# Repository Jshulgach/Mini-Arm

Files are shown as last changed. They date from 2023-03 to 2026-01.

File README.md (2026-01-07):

# Mini-Arm
<!-- ![](assets/assembly2.png) -->
<div align=center>

<p align="center">
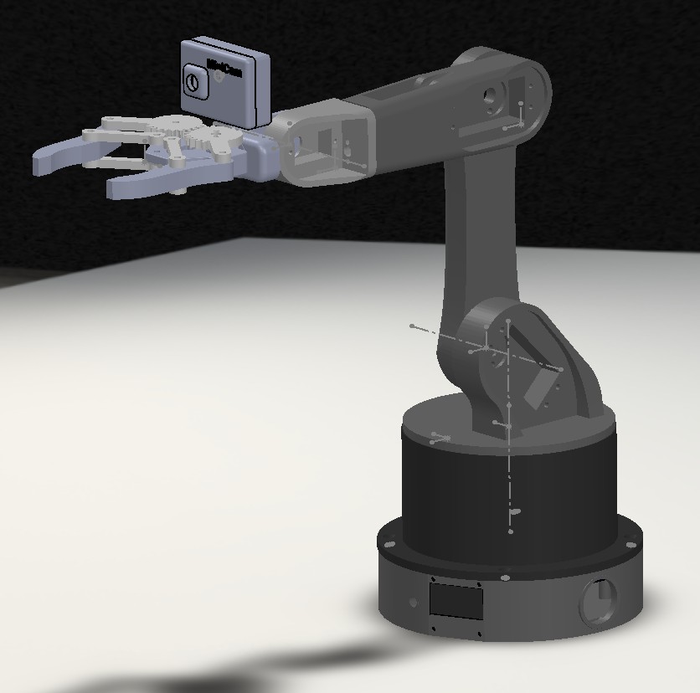
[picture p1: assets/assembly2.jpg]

</p>

</div>







**[📖 Documentation](https://jshulgach.github.io/Mini-Arm/)** | **[🚀 Quick Start](https://jshulgach.github.io/Mini-Arm/getting_started/quickstart.html)** | **[🔧 Hardware Guide](https://jshulgach.github.io/Mini-Arm/hardware/assembly.html)**

The Mini Arm is a miniature version of the [Desktop-Arm](https://github.com/Jshulgach/Desktop-Arm) project, a portable 6DOF 3D-printed open-source robot arm. Plug in a USB cable and immediately enjoy these features:

+ Runs on Raspberry Pico 2 microcontroller using [CircuitPython](https://circuitpython.org/)
+ Internal IK solver to handle joint state calculations on the microcontroller!
+ 95% 3D printable components (aside from nuts & bolts)
+ Total parts cost <= $100
+ Weighs less than 1lb (~0.3kg)

These install instructions were tailored using a Windows 10 OS. There are also setup instructions for [Ubuntu](https://www.gibbard.me/using_the_raspberry_pi_pico_on_ubuntu/) and the [Raspberry Pi](https://www.tomshardware.com/how-to/raspberry-pi-pico-setup) too.

## Contents
- [Repository Structure](#repository-structure)
- [Installation](#installation)
  - [Software](#software)
  - [Hardware](#hardware)
- [Demos](#demos)
  - [Xbox Teleop](#xbox-teleop)
  - [Face Detection](#face-detection)
- [Tests](#tests)
- [Multimodal agentic AI Integration](#multimodal-agentic-ai-integration)
- [AJ GUI](#aj-gui)
- [ROS2 Robot Visualizer](#ros2-robot-visualizer)
- [Acknowledgements](#acknowledgements)

# Repository Structure 

This repository contains everything needed to build, program, and control the Mini-Arm robot:

```
Mini-Arm/
├── ros2/                  # ROS2 packages (also contains Python client)
│   ├── miniarm_core/          # Python client library (pip installable)
│   │   └── miniarm_core/
│   │       ├── client.py      # MiniArmClient class
│   │       └── __main__.py    # CLI entry point
│   ├── miniarm_description/   # URDF & meshes
│   ├── miniarm_moveit_config/ # MoveIt2 configuration
│   └── miniarm_servo/         # Real-time servo control
├── firmware/              # Embedded firmware
│   └── circuitpython/     # CircuitPython for Raspberry Pi Pico
│       ├── code.py        # Main firmware
│       ├── lib/           # CircuitPython libraries
│       └── *.uf2          # Pre-built firmware images
├── hardware/              # Physical build resources
│   ├── cad/solidworks/    # SolidWorks CAD files (.SLDPRT, .SLDASM)
│   ├── stl/               # 3D printable STL files
│   └── bom/               # Bill of Materials
├── examples/              # Usage examples and demos
├── tests/                 # Test scripts
├── docs/                  # Documentation (Sphinx)
└── pyproject.toml         # Python package configuration
```

**Key components:**
- `ros2/miniarm_core/` - Pip-installable Python package for controlling the robot
- `firmware/circuitpython/` - CircuitPython firmware for the Raspberry Pi Pico
- `hardware/` - CAD files, STL meshes, and bill of materials
- `ros2/` - ROS2 packages for visualization and advanced control

## Installation

### Python Package

Install the Mini-Arm Python package directly from GitHub:

```bash
# Install from GitHub
pip install git+https://github.com/Jshulgach/Mini-Arm.git

# Or clone and install in development mode
git clone https://github.com/Jshulgach/Mini-Arm.git
cd Mini-Arm
pip install -e .
```

### ROS2 Installation (All Packages)

For ROS2 users, all packages can be built together:

```bash
# Create workspace
mkdir -p ~/miniarm_ws/src
cd ~/miniarm_ws/src

# Clone and symlink
git clone https://github.com/Jshulgach/Mini-Arm.git
ln -s Mini-Arm/ros2/* .

# Build
cd ~/miniarm_ws
colcon build
source install/setup.bash
```

### Firmware Setup

1. **Choose Pico firmware**

    We have provided CircuitPython firmware for both the Pico and Pico2! Find the `.uf2` files in `firmware/circuitpython/`, or download the latest [CircuitPython](https://circuitpython.org/) firmware for the [Pico](https://circuitpython.org/board/raspberry_pi_pico/) or [Pico 2](https://circuitpython.org/board/raspberry_pi_pico_2/). 

2. **Flash the firmware**
   - When you plug in the Pico for the first time with the BOOTSEL button held, a new drive will appear on your computer.
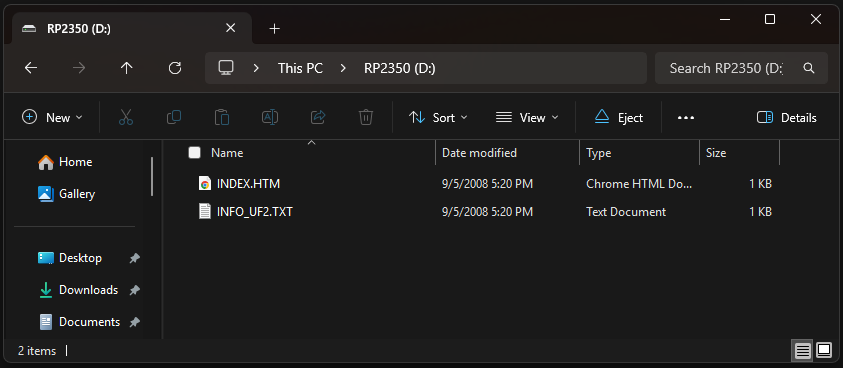
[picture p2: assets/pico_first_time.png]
   
   - Move/drag the `.uf2` file to the Pico drive. The Pico will automatically reboot.

3. **Copy the firmware files**
   - Copy the contents of `firmware/circuitpython/code.py` and `firmware/circuitpython/lib/` to the Pico drive.

### Hardware Assembly

1. **Building the arm**
   - Parts list available in [`hardware/bom/bom.xlsx`](hardware/bom/bom.xlsx)
   - STL files for 3D printing in [`hardware/stl/`](hardware/stl/)
   - SolidWorks CAD source files in [`hardware/cad/solidworks/`](hardware/cad/solidworks/)
   - Assembly instructions at [HowToMechatronics](https://howtomechatronics.com/tutorials/arduino/diy-arduino-robot-arm-with-smartphone-control/)

2. **Electrical wiring**

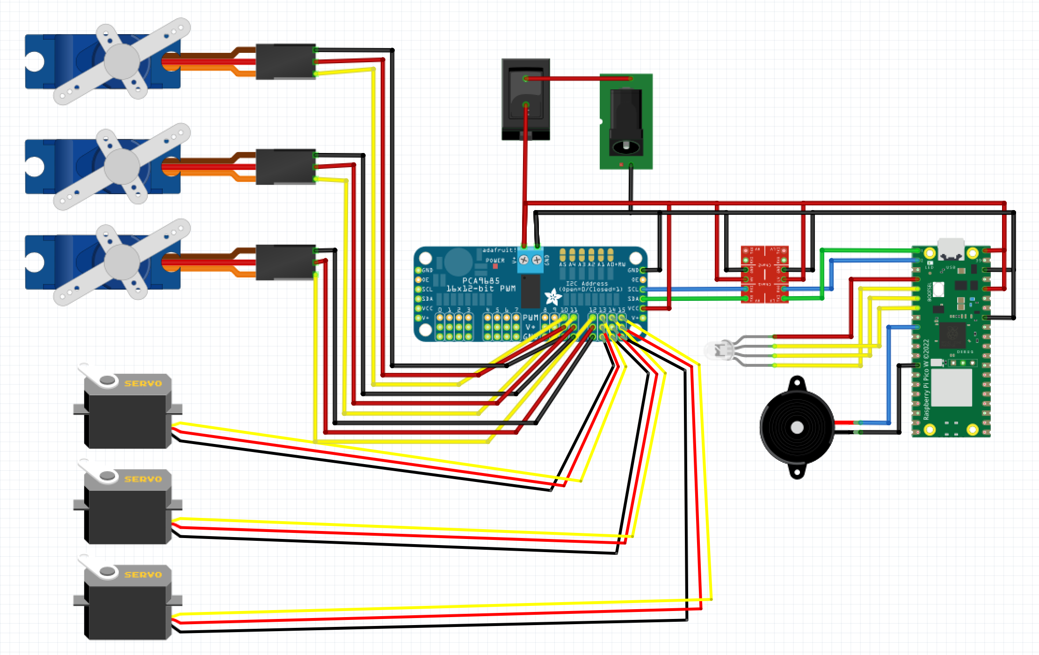
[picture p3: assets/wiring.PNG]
   

---
## Quick Start

### Command Line Interface

After installing the package, use the CLI:

```bash
# Get list of available commands
mini-arm --port COM3

# Or run as a module
python -m mini_arm --port COM3

# Send a specific command
mini-arm --port COM3 --command "get_pose"

# Interactive mode
mini-arm --port COM3 --interactive
```

### Python API

Use the `MiniArmClient` class in your own scripts:

```python
from miniarm_core import MiniArmClient

# Connect to Mini-Arm
client = MiniArmClient(port='COM3', baudrate=115200, verbose=True)

# Send commands
client.send('help')        # List available commands
client.home()              # Move to home position
client.send('get_pose')    # Get current position
client.set_pose(0.135, 0.0, 0.22)  # Move to position

# Context manager support
with MiniArmClient(port='COM3') as client:
    client.home()
    pose = client.get_pose()
    print(f"Current pose: {pose}")
```
```

### Available Commands

The Mini-Arm supports the following commands:
``` 
================================= List of commands =============================================
 movemotor   |  MOTOR VALUE     | // Moves motor A to absolute position B (deg)
 movemotors  |  VALUES          | // Moves motors absolute position B (deg) assimung VALUES is a list
 info        |                  | // Prints info about robot system (motors, grippers, and sensors)
 set_gripper |  VALUE, STRING   | // Gripper command to set the state (open/close) or position
 set_pose    |  VALUES          | // Updates the end effector pose to an absolute cartesian coordinate pose. Pass a list of values (ex: [X,Y,Z] or [X,Y,Z,R,P,Y])
 get_pose    |                  | // Returns the current position and orientation of the robot end effector
 set_joints  |  (DISABLED)      | // Updates the robot joint state. Pass a list of values (ex: [0,0,0,0,0,0])
 get_joints  |                  | // Returns the current robot joint state
 set_led     |  VALUES          | // Set the RGB LED to a specific color using 0-255 values in a 3-element list
 set_delta   |  VALUES          | // Updates the end effector pose with a delta movement relative to the robot's current pose. Pass a list of values (ex: [X,Y,Z] or [X,Y,Z,R,P,Y])
 posture     |  (DISABLED)      | // Updates the end effector pose with a Cartesian displacement relative to the robot's origin. Pass a list of values (ex: [X,Y,Z] or [X,Y,Z,R,P,Y])
 controller  |  (DISABLED)      | // Controller-specific message as a long ascii string with buttons and joystick data that gets converted into a delta position. Check 'xbox_utils' for message type details
 help        |                  | // Display available commands
 play_music  |  STRING          | // Play a music file 
 debug       |  STRING          | // Pass 'on' or 'off' to enable or disable the verbose output
 set_rate    |  VALUE           | // Update the main loop rate (Hz)
 trajectory  |  STRING [REPEAT] | // Perform a specified trajectory (e.g. 'circle') with optional repeat argument (true/false)
 stop        |                  | // Stop ongoing traetories
 fsr         |                  | // Read the sensor values from the FSRs
 home        |                  | // Set the robot to its home position
 test        |                  | // Test command to verify output from device
 ================================================================================================
```

---
## Examples

See the `examples/` directory for detailed usage examples:

### [Basic Control](examples/01_basic_control/)
- `basic_demo.py` - Connect and send simple commands
- `position_control.py` - Move end effector to XYZ coordinates
- `gripper_control.py` - Open/close gripper

### [Trajectory Execution](examples/02_trajectory/)
- `circle_trajectory.py` - Execute circular trajectories in 3D space

### [Xbox Controller Teleop](examples/02_xbox_teleop/)
![](assets/xboxcontroller.png)

Control the arm with an Xbox controller in real-time:

```bash
cd examples/02_xbox_teleop
python xbox-client.py --port COM3
```

**Features:**
- Real-time end effector control via joysticks
- Gripper control with triggers
- LED status indicators (green = connected)

### [Motion Analysis](examples/03_analysis/)
- `trajectory_command.py` - Generate and execute trajectories
- `trajectory_comparison.py` - Compare commanded vs actual motion
- `convert_c3d_to_csv.py` - Process motion capture data
- `compute_alignment_transform.py` - Align coordinate frames

---

## Tests

Test scripts are organized by functionality in the `tests/` directory:

- **hardware/** - Serial communication and servo control tests
- **kinematics/** - Inverse kinematics solver validation
- **networking/** - TCP/IP and camera streaming tests  
- **visualization/** - 3D rendering and simulation tests

See [tests/README.md](tests/README.md) for details on running tests.

## Multimodal agentic AI Integration

TBD

## AJ GUI
Robot control cana also be done through the Unity version of the "AJ" GUI v1 (Link coming soon), or an SSH terminal to the robot. FOR TCP/IP, quickest way using a python terminal:

## ROS2 Robot Visualizer

The Mini Arm can be visualized in RViz2 using the included ROS2 packages in the `ros2/` directory. Refer to the [build instructions](ros2/README.md) for more information.

<!-- ![](assets/rviz_view.png) -->
<div align=center>

<p align="center">
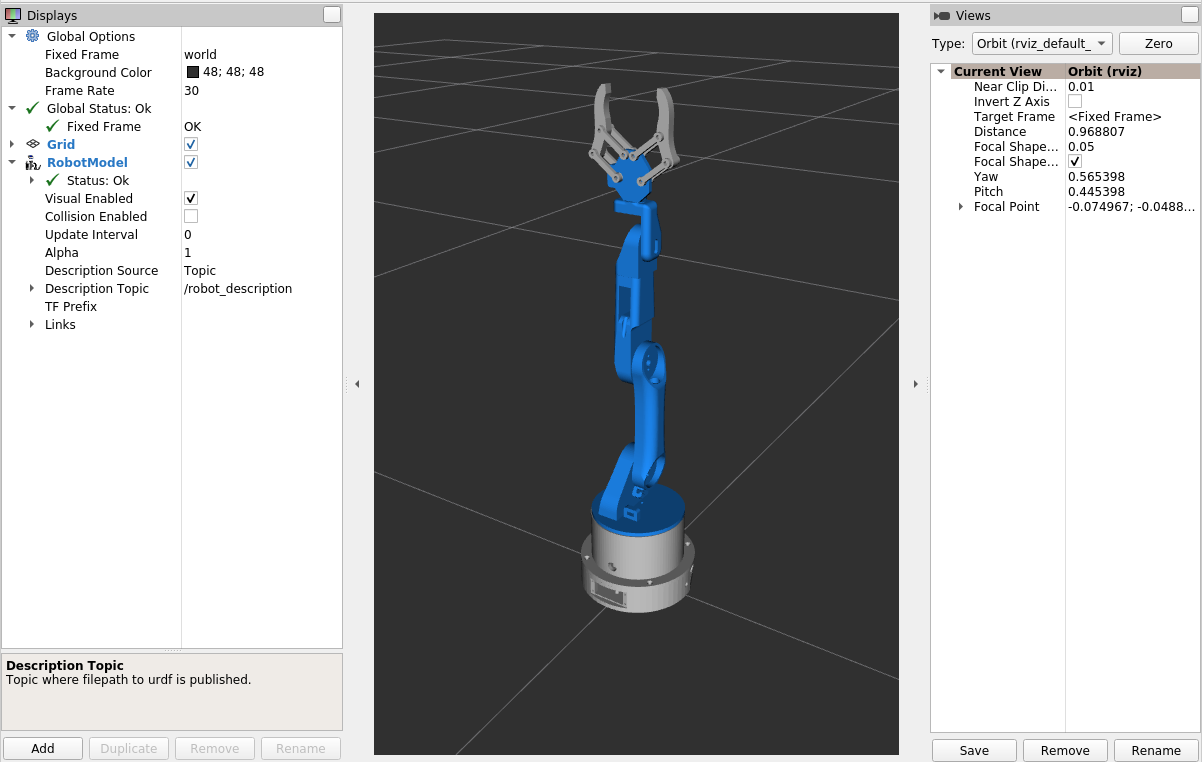
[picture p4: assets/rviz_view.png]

</p>

</div>

Feel free to reach out to me in case of any issues.  
If you find this repo useful in any way please do star ⭐️ it so that others can reap it's benefits as well!

## Acknowledgements
This project is inspired from the work done by:
 - [Alberto Abarzua](https://github.com/alberto-abarzua/3d_printed_robot_arm)
 - [Mithi Sevilla](https://github.com/mithi/arm-ik) 
 - [Zenetio](https://github.com/zenetio/RoboND-Kinematics-Project)
 - [Ohara124c41](https://github.com/Ohara124c41/RoboND-Kinematics-Kuka-KR210). 
 - [NitishPuri](https://github.com/NitishPuri/RoboND-Kinematics-Project/)

## License
Copyright 2022-2023 [Jonathan Shulgach](https://www.linkedin.com/in/jonathan-shulgach/)

This Source Code Form is subject to the terms of the Mozilla Public License, v. 2.0. If a copy of the MPL was not distributed with this file, you can obtain one at https://mozilla.org/MPL/2.0/.

[uf2]: (https://fileinfo.com/extension/uf2)
[CircuitPython]: (https://circuitpython.org/)
[PuTTY]: (https://putty.org/)

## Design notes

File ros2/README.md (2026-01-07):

# Mini-Arm ROS2 packages

This folder contains several RPS2 packages for using the arm in ROS2. Package building using `colcon` is recommended.

- Clone the Mini-Arm repo into your ROS2 workspace if you haven't done so:
    ```bash
    cd /your/ros2/workspace/src
    git clone https://github.com/Jshulgach/Mini-Arm.git
    ```
- Install dependencies using rosdep:
    ```bash
    rosdep install --from-paths src --ignore-src -r -y
    ```
  
- Build the packages using `colcon`:
    ```bash
    cd ..
    colcon build --packages-select miniarm_description miniarm_servo miniarm_moveit_config
    ```
- Source the workspace. For linux:
    ```bash 
    source install/setup.bash
    ```
- For Windows:
    ```cmd
    call install/setup.bat
    ```
  
Refer to the individual packages for usage instructions. 

<!-- There's also support for [ROS](https://ubuntu.com/blog/getting-started-with-micro-ros-on-raspberry-pi-pico) on the microcontroller if you want a challenge... -->

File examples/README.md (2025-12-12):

# Mini-Arm Examples

Organized examples demonstrating Mini-Arm control, from basic commands to advanced motion analysis.

## Directory Structure

```
examples/
├── 01_basic_control/      # Simple control scripts
│   ├── basic_demo.py      # Connect and send commands
│   ├── position_control.py# Cartesian position control
│   ├── gripper_control.py # Gripper open/close
│   └── README.md
├── 02_trajectory/         # Trajectory execution
│   ├── circle_trajectory.py
│   └── README.md
├── 02_xbox_teleop/        # Xbox controller control
│   └── xbox-client.py
└── 03_analysis/           # Motion analysis tools
    ├── trajectory_command.py
    ├── trajectory_comparison.py
    ├── convert_c3d_to_csv.py
    ├── compute_alignment_transform.py
    ├── utils.py
    └── README.md
```

## Getting Started

### Installation

Ensure Mini-Arm package is installed:

```bash
pip install -e .
```

Or install dependencies:

```bash
pip install -r requirements.txt
```

### Hardware Setup

1. Connect Mini-Arm via USB
2. Find serial port:
   - **Windows**: Check Device Manager (usually COM3, COM4, etc.)
   - **Linux**: `ls /dev/ttyACM*` or `/dev/ttyUSB*`
   - **Mac**: `ls /dev/tty.usb*`

3. Verify connection:
```bash
python mini_arm.py --port COM3 --command "test"
```

## Example Categories

### 01 - Basic Control

Learn fundamental Mini-Arm control:
- Serial communication
- Sending commands
- Position control
- Gripper operation

**Start here if you're new!**

### 02 - Trajectory Execution

Execute predefined motion paths:
- Circular trajectories
- Custom waypoint sequences
- Smooth interpolation

### 02 - Xbox Teleop

Real-time control with Xbox controller:
- Joystick control
- Button mapping
- LED feedback

### 03 - Analysis

Advanced motion analysis:
- Trajectory generation
- Performance evaluation
- Motion capture integration
- Coordinate frame alignment

## Common Usage Patterns

### Send a Single Command

```python
from mini_arm import MiniArmClient

client = MiniArmClient(port='COM3')
client.send('home')
client.disconnect()
```

### Execute a Sequence

```python
from mini_arm import MiniArmClient
import time

client = MiniArmClient(port='COM3')

commands = [
    'home',
    'set_pose:[0.15, 0.0, 0.22]',
    'set_gripper:close',
    'set_delta:[0.0, 0.0, 0.05]',
    'set_gripper:open'
]

for cmd in commands:
    client.send(cmd)
    time.sleep(1)

client.disconnect()
```

### Read Response

```python
client = MiniArmClient(port='COM3', verbose=True)
client.send('get_pose')
time.sleep(0.5)
response = client.get_buffer()
print(response)
```

## Troubleshooting

**Can't find serial port:**
```bash
# Windows
mode  # List COM ports

# Linux
ls /dev/tty*  # List all serial devices
```

**Connection fails:**
- Check USB cable
- Verify Pico is running CircuitPython
- Try different USB port
- Check serial permissions (Linux: add user to `dialout` group)

**Commands not working:**
- Send `test` command to verify connection
- Check baudrate matches Pico settings (default: 9600)
- Look for error messages in serial output
- Verify firmware is up to date

**Unexpected behavior:**
- Always call `home` before complex movements
- Check workspace limits
- Verify servo calibration
- Monitor for servo overheating

## Safety Guidelines

⚠️ **Important:**
- Keep workspace clear of obstacles
- Start with slow, small movements
- Monitor servo temperatures
- Have emergency stop ready
- Never leave unattended during operation

## Next Steps

1. **Try basic examples** - Start with `01_basic_control/basic_demo.py`
2. **Experiment** - Modify examples for your use case
3. **Create custom trajectories** - Use `02_trajectory/` as template
4. **Integrate sensors** - Add camera, force sensors, etc.
5. **Develop applications** - Pick-and-place, drawing, etc.

## Resources

- [Main README](../README.md) - Project overview
- [Hardware Setup](../README.md#hardware) - Assembly and wiring
- [Tests](../tests/README.md) - Validation scripts
- [ROS2 Packages](../miniarm_ros/README.md) - Visualization

## Contributing

Have a cool example? Submit a pull request!

Examples should:
- Include `--help` argument documentation
- Have clear comments
- Follow existing structure
- Include error handling

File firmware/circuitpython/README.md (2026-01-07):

# Pico Setup for Mini Arm

This readme contains the main firmware, scripts, and demos for a CircuitPython-controlled microcontroller. This project uses the [Raspberry Pico](https://www.raspberrypi.com/documentation/microcontrollers/pico-series.html) as an inexpensive option for handling kinematic calculations and hardware control. This package does NOT use any symbolic math packagaes, only numpy, which makes this scalable to microcontrollers with the same kinematic configuration!

## Raspberry Pico Setup:

See [Getting Started with the Raspberry Pi Pico](https://rptl.io/pico-get-started) and the README in the [pico-sdk](https://github.com/raspberrypi/pico-sdk) for information
on getting up and running. These instructions should work with both Pico 1 and 2.

###  Configure the Raspberry Pico for Circuitpython (Skip if already done):

1. If this is the first time the Pico is used, or a new CircuitPython image is needed, enter bootloader mode by holding down the button on the Pico while plugging it into the computer. The Pico should show up as a USB drive named `RPI-RP2`, `CIRCUITPY`, or `BOOT`.
2. Move the pre-built CircuitPython UF2 file to the Pico drive. A CircuitPython image (8.4.0) for the pico has already been provided. More recent UF2 files can be downloaded from the [Circuitpython website](https://circuitpython.org/board/raspberry_pi_pico/). 

### Install the Circuitpython Libraries:

1. Remove any files in the `lib` folder on the Pico and replace them with the contents of the `lib` folder in this repository.
2. Move the `code.py` file to the root of the Pico drive.
3. (Optional) If you want to connect the Pico to a wireless network, edit the `settings.toml` file with your network credentials and change the `COMM_TYPE` to `NETWORK`.

The code will automatically run when the Pico is powered on, like code flashed onto an Arduino.

## Quick Start

### Serial Communication:
1. Connect the Pico to your computer using a USB cable.
2. Configure the `code.py` to make sure the `use_serial` argument is set to `True`.
3. 3Open a serial console and connect to the Pico's COM port. Check your system's devices to see which COM port the Pico is connected to (e.g. `COM3` for Windows devices, `/dev/ttyACM0` for Linux).

- Using a ssh serial client like [PuTTY](https://www.putty.org/) is a good option since it allows terminal messages to be sent as well as received.
- If using python, the `pyserial` library can be used to open a serial connection:
```python
import serial
s = serial.Serial('COM3', 115200)
```
You can send commands as string messages. For example to open the gripper:
```python
s.write(b"gripper:open;")
```

### TCP/IP Network Communication:
1. Update the `settings.toml` file to your network credentials.
2. Configure your `code.py` file to enable the network communication type by setting `use_wifi` to `True`.
3. Restart the Pico by pressing `Ctrl+d` in the serial console (if connected) or cycling the power.

Sending messages to the pico over the network can be done using the `socket` library in python. The Pico will listen on port `5001` for incoming messages, but can also be comfigured.
```python
import socket
s = socket.socket(socket.AF_INET, socket.SOCK_STREAM)
s.connect(('127.0.0.1', 65432))
```
Send messages like you would send strings over a serial connection. For example, set the global pose with: 
```python
s.send(b"pose:[0.135,0,0.2,0,0,0];")
```

### Robot controller commands

The full list of commands with the expentant structure is below:

| Name | Parameters | Description |
|---|---|---|
| movemotor  | MOTOR VALUE | Moves motor A to absolute position B (deg) | 
| movemotors | VALUES | Moves motors absolute position B (deg) assimung VALUES is a list |
| info | | Prints info about robot system (motors, grippers, and sensors) |
| gripper | VALUE | Gripper command to set the state (open/close) or position |
| pose | VALUES | Updates the end effector pose to an absolute cartesian coordinate pose. Pass a list of values (ex: [X,Y,Z] or [X,Y,Z,R,P,Y]) |
| delta | VALUES | Updates the end effector pose with a delta movement relative to the robot's current pose. Pass a list of values (ex: [X,Y,Z] or [X,Y,Z,R,P,Y]) |
| posture | VALUES | Updates the end effector pose with a delta movement relative to the robot's  origin. Pass a list of values (ex: [X,Y,Z] or [X,Y,Z,R,P,Y]) |
| controller | | Controller-specific message as a long ascii string with buttons and joystick data that gets converted into a delta position. Check 'xbox_utils' for message type details | 
| help | | Display available commands |
| play_music | STRING | Play a music file (limited to starwars or mii, but enjoyable nonetheless) |
| led | VALUES | Set the RGB LED to a specific color using 0-255 values in a 3-element list |
| debug | STRING | Pass 'on' or 'off' to enable or disable the verbose output |
| rate | VALUE | Update the main loop rate (Hz) |
| trajectory | STRING [REPEAT] | Perform a specified trajectory (e.g. 'circle') with optional repeat argument (true/false) |
| stop | | Stop ongoing traetories |
| fsr | | Read the sensor values from the FSRs |
| home | | Set the robot to its home position |
| test | | Test command to verify output from device |

#### Note:

1) All commands received must end with the `;` terminator string. 
2) Arguments must be split with the `:` string (`,` can also be used). For example, to move motor 1 to 90 degrees, the message would be `movemotor:1:90;`.

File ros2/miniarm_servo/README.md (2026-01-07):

# Mini-Arm Servo 

Repository for the Mini-Arm Servo ROS package. This package is responsible for controlling the servo motors of the Mini-Arm.

## Robot Visualization Demo

Open a terminal with the ROS2 libraries as well as your workspace sourced. RUn the command below to launch the Mini-Arm visualizer demo in RViz2:

```bash
ros2 launch miniarm_servo show_robot.launch.py
```

In the RViz2 Displays panel, in "Gobal Options" set "fixed frame" to `world`. Add a "RobotModel" display and set "Description Topic" to `/robot_description`.

Now you can play with the robot joint positions using the sliders in the "Joint State" GUI panel.

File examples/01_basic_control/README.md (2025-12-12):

# Basic Control Examples

Simple examples demonstrating basic Mini-Arm control via serial communication.

## Examples

### basic_demo.py

Connect to Mini-Arm and demonstrate basic commands:

```bash
python basic_demo.py --port COM3 --verbose
```

**Features:**
- List available commands
- Get current pose and joint states
- Move to home position
- Control LED color

**Arguments:**
- `--port` - Serial port (default: COM3, Linux: /dev/ttyACM0)
- `--baudrate` - Baudrate (default: 9600)
- `--verbose` - Enable verbose output

---

### position_control.py

Move the end effector to a specific XYZ position:

```bash
python position_control.py --x 0.15 --y 0.05 --z 0.20
```

**Features:**
- Cartesian position control (X, Y, Z)
- Automatic homing before movement
- Position verification

**Arguments:**
- `--port` - Serial port
- `--x` - Target X position in meters (default: 0.135)
- `--y` - Target Y position in meters (default: 0.0)
- `--z` - Target Z position in meters (default: 0.22)
- `--verbose` - Enable verbose output

---

### gripper_control.py

Control the gripper state:

```bash
# Cycle through open/close
python gripper_control.py --action cycle

# Open gripper
python gripper_control.py --action open

# Close gripper
python gripper_control.py --action close

# Set specific position (0.0 = closed, 1.0 = open)
python gripper_control.py --position 0.5
```

**Features:**
- Open/close gripper
- Set specific gripper position
- Cycle through states for testing

**Arguments:**
- `--port` - Serial port
- `--action` - Gripper action: open, close, or cycle (default: cycle)
- `--position` - Set specific position 0.0-1.0
- `--verbose` - Enable verbose output

---

## Prerequisites

Install the Mini-Arm package:

```bash
pip install -e .
```

Or ensure `mini_arm.py` is in your Python path.

## Wiring

Ensure Mini-Arm is properly wired and powered. See main [README](../../README.md#hardware) for wiring diagram.

## Troubleshooting

**Connection fails:**
- Check serial port (Windows: Device Manager, Linux: `ls /dev/tty*`)
- Verify baudrate matches Pico settings (default: 9600)
- Ensure Pico is powered and running CircuitPython

**Commands not working:**
- Send `help` command to verify connection
- Check Pico serial output for errors
- Verify firmware is up to date

**Unexpected movements:**
- Always call `home` before complex movements
- Check workspace limits in Pico code
- Verify servo calibration

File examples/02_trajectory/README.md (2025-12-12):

# Trajectory Examples

Examples for executing predefined trajectories with the Mini-Arm.

## Examples

### circle_trajectory.py

Execute a circular trajectory in 3D space:

```bash
# Circle in XY plane (horizontal)
python circle_trajectory.py --plane xy --radius 0.03

# Circle in XZ plane (vertical, front)
python circle_trajectory.py --plane xz --radius 0.04

# Circle in YZ plane (vertical, side)
python circle_trajectory.py --plane yz --radius 0.025
```

**Features:**
- Generate circular paths in any plane (XY, XZ, YZ)
- Configurable center, radius, and number of points
- Adjustable delay between waypoints
- Smooth trajectory execution

**Arguments:**
- `--port` - Serial port (default: COM3)
- `--center` - Circle center [X Y Z] in meters (default: 0.135 0.0 0.22)
- `--radius` - Circle radius in meters (default: 0.03)
- `--points` - Number of waypoints (default: 20)
- `--plane` - Plane for circle: xy, xz, or yz (default: xy)
- `--delay` - Delay between points in seconds (default: 0.5)
- `--verbose` - Enable verbose output

**Examples:**

```bash
# Small, fast circle
python circle_trajectory.py --radius 0.02 --points 12 --delay 0.3

# Large, smooth circle
python circle_trajectory.py --radius 0.05 --points 40 --delay 0.4

# Custom center position
python circle_trajectory.py --center 0.15 0.02 0.20 --radius 0.03
```

---

## Creating Custom Trajectories

You can create custom trajectories by generating lists of [X, Y, Z] points:

```python
from mini_arm import MiniArmClient
import time

# Connect to Mini-Arm
client = MiniArmClient(port='COM3')

# Define custom trajectory (square)
square = [
    [0.13, 0.03, 0.22],
    [0.16, 0.03, 0.22],
    [0.16, -0.03, 0.22],
    [0.13, -0.03, 0.22],
    [0.13, 0.03, 0.22],  # Close the square
]

# Execute
for point in square:
    client.send(f'set_pose:{point}')
    time.sleep(0.5)
```

## Workspace Limits

Be aware of Mini-Arm workspace limits:
- **X**: 0.10 to 0.20 meters (forward/back)
- **Y**: -0.10 to 0.10 meters (left/right)
- **Z**: 0.10 to 0.30 meters (up/down)

Points outside this range may cause errors or unexpected behavior.

## Safety Tips

⚠️ **Important:**
- Always test trajectories with small radius first
- Ensure workspace is clear of obstacles
- Keep emergency stop accessible
- Monitor for servo overheating on long trajectories
- Use appropriate delays to avoid jerky motion

## Troubleshooting

**Robot doesn't follow circle:**
- Reduce radius if hitting workspace limits
- Increase delay for smoother motion
- Check IK solver is working (send `info` command)

**Trajectory execution stops:**
- Check serial connection
- Verify Pico isn't overloaded (reduce trajectory points)
- Ensure power supply is adequate

**Position drift:**
- Calibrate servos
- Check for mechanical binding
- Verify commanded vs actual positions

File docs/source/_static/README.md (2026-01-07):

# Mini-Arm Static Assets

This folder contains static assets for the documentation:

## Required Images

Please add the following images for full documentation support:

- `mini-arm-logo.png` - Logo for documentation header
- `mini-arm-banner.jpg` - Banner image for landing page
- `favicon.ico` - Browser favicon

### Assembly Images
Create an `assembly/` subfolder with:
- `step1_base.jpg`
- `step2_shoulder.jpg`
- `step3_upper_arm.jpg`
- `step4_forearm.jpg`
- `step5_wrist.jpg`
- `step6_electronics.jpg`

### ROS2 Images
Create a `ros2/` subfolder with:
- `rviz_interactive.png`
- `moveit_rviz.png`

## Image Guidelines

- Use high-resolution images (at least 800px wide)
- Optimize for web (compress PNG/JPG)
- Include alt text in RST files

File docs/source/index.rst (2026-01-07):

Mini-Arm Documentation
======================

Mini-Arm Robot

|

**Mini-Arm** is a miniature 6-DOF 3D-printed robot arm with an onboard inverse kinematics solver,
CircuitPython firmware, and full ROS2 integration—all for under $100.

.. grid:: 2

    .. grid-item-card:: 🚀 Getting Started
        :link: getting_started/installation
        :link-type: doc

        Install the software and get your Mini-Arm up and running in minutes.

    .. grid-item-card:: 🔧 Hardware Guide
        :link: hardware/assembly
        :link-type: doc

        Build your own Mini-Arm with our step-by-step assembly instructions.

    .. grid-item-card:: 📖 Tutorials
        :link: tutorials/index
        :link-type: doc

        Learn through hands-on examples from basic control to AI integration.

    .. grid-item-card:: 📚 API Reference
        :link: api/modules
        :link-type: doc

        Complete Python API documentation for the MiniArm client library.

Key Features
------------

- **Raspberry Pi Pico 2** - Runs CircuitPython firmware with onboard IK solver
- **Under $100** - Affordable robotics for education and research
- **95% 3D Printable** - Only fasteners and servos required
- **ROS2 Integration** - Full MoveIt2 support for motion planning
- **Python API** - Simple, intuitive control from any Python environment
- **Lightweight** - Less than 1 lb (~0.3 kg)

.. toctree::
   :maxdepth: 1
   :caption: Getting Started
   :hidden:

   getting_started/installation
   getting_started/quickstart
   getting_started/configuration

.. toctree::
   :maxdepth: 1
   :caption: Hardware
   :hidden:

   hardware/bom
   hardware/3d_printing
   hardware/assembly
   hardware/wiring

.. toctree::
   :maxdepth: 1
   :caption: Tutorials
   :hidden:

   tutorials/index
   tutorials/basic_control
   tutorials/trajectories
   tutorials/xbox_teleop
   tutorials/face_tracking
   tutorials/ai_integration

.. toctree::
   :maxdepth: 1
   :caption: API Reference
   :hidden:

   api/modules

.. toctree::
   :maxdepth: 1
   :caption: ROS2 Integration
   :hidden:

   ros2/setup
   ros2/visualization
   ros2/moveit

.. toctree::
   :maxdepth: 1
   :caption: Resources
   :hidden:

   resources/faqs
   resources/troubleshooting
   resources/contributing
   resources/publishing
   resources/changelog

Indices and tables
==================

* :ref:`genindex`
* :ref:`modindex`
* :ref:`search`

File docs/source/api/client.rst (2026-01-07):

MiniArmClient API
=================

.. module:: miniarm_core
   :synopsis: Mini-Arm robot control interface

The ``MiniArmClient`` class provides a complete interface for controlling the Mini-Arm robot via serial communication.

.. autoclass:: miniarm_core.MiniArmClient
   :members:
   :undoc-members:
   :show-inheritance:

Quick Reference
---------------

.. code-block:: python

    from miniarm_core import MiniArmClient

    # Connect to Mini-Arm
    client = MiniArmClient(port='COM3', baudrate=115200)
    
    # Or use context manager
    with MiniArmClient(port='COM3') as client:
        client.home()
        client.set_pose(0.135, 0.0, 0.22)

Constructor
-----------

.. code-block:: python

    MiniArmClient(
        name: str = 'MiniArmClient',
        port: str = 'COM3',
        baudrate: int = 115200,
        command_delimiter: str = ';',
        timeout: float = 1.0,
        verbose: bool = False
    )

**Parameters:**

- **name** (*str*) - Identifier for the client instance
- **port** (*str*) - Serial port (``COM3`` on Windows, ``/dev/ttyACM0`` on Linux)
- **baudrate** (*int*) - Serial baud rate. Default: 115200
- **timeout** (*float*) - Read timeout in seconds. Default: 1.0
- **verbose** (*bool*) - Enable verbose logging. Default: False

Motion Commands
---------------

home()
^^^^^^

Move the robot arm to its home position.

.. code-block:: python

    client.home()

set_pose(x, y, z, roll=0, pitch=0, yaw=0)
^^^^^^^^^^^^^^^^^^^^^^^^^^^^^^^^^^^^^^^^^

Move the end-effector to a Cartesian position.

:param x: X coordinate in meters
:param y: Y coordinate in meters
:param z: Z coordinate in meters
:param roll: Roll angle in radians (optional)
:param pitch: Pitch angle in radians (optional)
:param yaw: Yaw angle in radians (optional)

.. code-block:: python

    # Move to position
    client.set_pose(0.135, 0.0, 0.22)
    
    # With orientation
    client.set_pose(0.15, 0.05, 0.20, roll=0, pitch=0.5, yaw=0)

set_delta_pose(dx=0, dy=0, dz=0, droll=0, dpitch=0, dyaw=0)
^^^^^^^^^^^^^^^^^^^^^^^^^^^^^^^^^^^^^^^^^^^^^^^^^^^^^^^^^^^

Move the end-effector by a relative delta.

.. code-block:: python

    # Move 1cm in X direction
    client.set_delta_pose(dx=0.01)
    
    # Move diagonally
    client.set_delta_pose(dx=0.01, dy=0.01, dz=-0.005)

get_pose()
^^^^^^^^^^

Get the current end-effector position.

:returns: numpy array [x, y, z] or None

.. code-block:: python

    pose = client.get_pose()
    print(f"Position: x={pose[0]:.3f}, y={pose[1]:.3f}, z={pose[2]:.3f}")

Joint Commands
--------------

set_joint(joint_index, angle)
^^^^^^^^^^^^^^^^^^^^^^^^^^^^^

Move a single joint to a specified angle.

:param joint_index: Joint index (0-5 for arm, 6 for gripper)
:param angle: Target angle in degrees

.. code-block:: python

    client.set_joint(0, 45)   # Base joint to 45°
    client.set_joint(2, 90)   # Elbow to 90°

set_joints(angles)
^^^^^^^^^^^^^^^^^^

Set all joint angles simultaneously.

:param angles: List of joint angles in degrees

.. code-block:: python

    client.set_joints([0, 45, 90, 0, 45, 0])
    
    # Include gripper position
    client.set_joints([0, 45, 90, 0, 45, 0, 90])

get_joints()
^^^^^^^^^^^^

Get current joint angles.

:returns: List of joint angles in degrees

.. code-block:: python

    joints = client.get_joints()
    for i, angle in enumerate(joints):
        print(f"Joint {i}: {angle}°")

Gripper Commands
----------------

set_gripper(value)
^^^^^^^^^^^^^^^^^^

Control the gripper position.

:param value: Position (0-180 degrees) or state ('open', 'close')

.. code-block:: python

    client.set_gripper(90)      # Set to 90°
    client.set_gripper('open')  # Fully open
    client.set_gripper('close') # Fully close

gripper_open() / gripper_close()
^^^^^^^^^^^^^^^^^^^^^^^^^^^^^^^^

Convenience methods for gripper control.

.. code-block:: python

    client.gripper_open()
    client.gripper_close()

LED Commands
------------

set_led(r, g, b)
^^^^^^^^^^^^^^^^

Set the RGB LED color.

:param r: Red value (0-255)
:param g: Green value (0-255)
:param b: Blue value (0-255)

.. code-block:: python

    client.set_led(255, 0, 0)    # Red
    client.set_led(0, 255, 0)    # Green
    client.set_led(0, 0, 255)    # Blue

Convenience methods:

.. code-block:: python

    client.led_red()
    client.led_green()
    client.led_blue()
    client.led_off()

Trajectory Commands
-------------------

start_trajectory(trajectory, repeat=False)
^^^^^^^^^^^^^^^^^^^^^^^^^^^^^^^^^^^^^^^^^^

Start a predefined trajectory.

:param trajectory: Trajectory name (e.g., 'circle')
:param repeat: Whether to loop continuously

.. code-block:: python

    client.start_trajectory('circle')
    client.start_trajectory('circle', repeat=True)

stop_trajectory()
^^^^^^^^^^^^^^^^^

Stop any running trajectory.

.. code-block:: python

    client.stop_trajectory()

System Commands
---------------

get_info()
^^^^^^^^^^

Get robot system information.

.. code-block:: python

    client.get_info()

get_help()
^^^^^^^^^^

Display available firmware commands.

.. code-block:: python

    client.get_help()

set_debug(enabled)
^^^^^^^^^^^^^^^^^^

Enable or disable debug output on the robot.

.. code-block:: python

    client.set_debug(True)   # Enable
    client.set_debug(False)  # Disable

set_rate(hz)
^^^^^^^^^^^^

Set the main loop rate on the robot.

.. code-block:: python

    client.set_rate(100)  # 100 Hz

read_fsr()
^^^^^^^^^^

Read force-sensitive resistor values from the gripper.

.. code-block:: python

    fsr_values = client.read_fsr()
    print(fsr_values)

Connection Management
---------------------

disconnect()
^^^^^^^^^^^^

Close the serial connection.

.. code-block:: python

    client.disconnect()

reconnect()
^^^^^^^^^^^

Attempt to reconnect after disconnect.

:returns: True if successful

.. code-block:: python

    if not client.connected:
        success = client.reconnect()

Context Manager
^^^^^^^^^^^^^^^

Use ``with`` statement for automatic cleanup:

.. code-block:: python

    with MiniArmClient(port='COM3') as client:
        client.home()
        client.set_pose(0.135, 0.0, 0.22)
    # Connection automatically closed

Class Attributes
----------------

- ``HOME_POSITION`` - Default home position [0.135, 0.0, 0.215]
- ``WORKSPACE_LIMITS`` - Dictionary of workspace bounds
- ``connected`` - Boolean indicating connection status

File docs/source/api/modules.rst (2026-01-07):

API Reference
=============

Complete API reference for the Mini-Arm Python library.

.. toctree::
   :maxdepth: 2

   client

Quick Reference
---------------

**Main Class:**

- :class:`mini_arm.MiniArmClient` - Robot control interface

**Installation:**

.. code-block:: bash

   pip install git+https://github.com/Jshulgach/Mini-Arm.git

**Basic Usage:**

.. code-block:: python

   from mini_arm import MiniArmClient
   
   with MiniArmClient(port='COM3') as client:
       client.home()
       client.set_pose(0.135, 0.0, 0.22)
       client.gripper_open()

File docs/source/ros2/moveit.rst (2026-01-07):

MoveIt2 Integration
===================

Use MoveIt2 for motion planning and manipulation.

Launch MoveIt2
--------------

.. code-block:: bash

    ros2 launch miniarm_moveit_config demo.launch.py

This starts:

- MoveIt2 motion planning
- RViz with MoveIt plugin
- Planning scene

With real robot:

.. code-block:: bash

    ros2 launch miniarm_moveit_config robot.launch.py

Interactive Planning
--------------------

In RViz, use the interactive marker to:

1. Drag the end-effector to a goal pose
2. Click "Plan" to compute trajectory
3. Click "Execute" to run on robot



Python Interface
----------------

.. code-block:: python

    import rclpy
    from rclpy.node import Node
    from moveit2 import MoveIt2

    def main():
        rclpy.init()
        node = Node('miniarm_moveit_example')

        moveit2 = MoveIt2(
            node=node,
            joint_names=[
                'joint_1', 'joint_2', 'joint_3',
                'joint_4', 'joint_5', 'joint_6'
            ],
            base_link_name='base_link',
            end_effector_name='tool0',
        )

        # Move to joint configuration
        moveit2.move_to_configuration([0.0, -0.5, 1.0, 0.0, 0.5, 0.0])

        # Move to pose
        from geometry_msgs.msg import Pose
        target_pose = Pose()
        target_pose.position.x = 0.1
        target_pose.position.y = 0.0
        target_pose.position.z = 0.15
        target_pose.orientation.w = 1.0

        moveit2.move_to_pose(target_pose)

        rclpy.shutdown()

    if __name__ == '__main__':
        main()

Planning Groups
---------------

The MoveIt config defines these planning groups:

- **arm** - All 6 joints (main manipulator)
- **gripper** - Gripper fingers

.. code-block:: python

    # Use specific planning group
    moveit2.move_to_configuration(
        [0.5, 0.5],  # 2 values for gripper fingers
        group_name='gripper'
    )

Collision Objects
-----------------

Add obstacles to the planning scene:

.. code-block:: python

    from moveit2 import PlanningScene
    from geometry_msgs.msg import Pose

    planning_scene = PlanningScene(node)

    # Add a box obstacle
    box_pose = Pose()
    box_pose.position.x = 0.1
    box_pose.position.y = 0.1
    box_pose.position.z = 0.025

    planning_scene.add_box(
        id='obstacle',
        pose=box_pose,
        size=[0.05, 0.05, 0.05]
    )

    # Now motion planning will avoid this box

Grasp Planning
--------------

Basic pick and place:

.. code-block:: python

    # Pre-grasp position (above object)
    moveit2.move_to_pose(pre_grasp_pose)

    # Open gripper
    moveit2.move_to_configuration([0.04, 0.04], group_name='gripper')

    # Approach (Cartesian path)
    moveit2.move_to_pose(grasp_pose, cartesian=True)

    # Close gripper
    moveit2.move_to_configuration([0.0, 0.0], group_name='gripper')

    # Lift
    moveit2.move_to_pose(lift_pose, cartesian=True)

    # Move to place location
    moveit2.move_to_pose(place_pose)

    # Release
    moveit2.move_to_configuration([0.04, 0.04], group_name='gripper')

Configuration Files
-------------------

Key config files in ``miniarm_moveit_config/config/``:

- ``miniarm.srdf`` - Semantic robot description
- ``joint_limits.yaml`` - Velocity/acceleration limits
- ``kinematics.yaml`` - IK solver configuration
- ``ompl_planning.yaml`` - OMPL planner settings

**Example kinematics.yaml:**

.. code-block:: yaml

    arm:
      kinematics_solver: kdl_kinematics_plugin/KDLKinematicsPlugin
      kinematics_solver_search_resolution: 0.005
      kinematics_solver_timeout: 0.05

**Example joint_limits.yaml:**

.. code-block:: yaml

    joint_limits:
      joint_1:
        has_velocity_limits: true
        max_velocity: 3.14  # rad/s
        has_acceleration_limits: true
        max_acceleration: 6.28  # rad/s^2

Next Steps
----------

- :doc:`setup` - ROS2 installation
- :doc:`visualization` - RViz configuration

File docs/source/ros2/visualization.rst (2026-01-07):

RViz Visualization
==================

Visualize your Mini-Arm in RViz2.

Basic Visualization
-------------------

Launch the robot description viewer:

.. code-block:: bash

    ros2 launch miniarm_bringup view_robot.launch.py

This opens RViz with:

- Robot model from URDF
- Joint state publisher GUI
- TF frames

Interactive Control
-------------------

Use the joint state publisher GUI to move joints interactively:



Real Robot Visualization
------------------------

Connect to the physical robot and visualize its state:

.. code-block:: bash

    ros2 launch miniarm_bringup robot.launch.py rviz:=true

The robot model will follow the real joint positions.

Custom RViz Configuration
-------------------------

Create a custom RViz config:

1. Launch RViz:

.. code-block:: bash

    rviz2

2. Add displays:
   
   - **RobotModel**: Topic = ``/robot_description``
   - **TF**: Show all transforms
   - **Marker**: Topic = ``/miniarm/workspace`` (optional)

3. Save configuration:

   File → Save Config As → ``my_miniarm.rviz``

4. Launch with custom config:

.. code-block:: bash

    ros2 launch miniarm_bringup view_robot.launch.py \
        rviz_config:=/path/to/my_miniarm.rviz

Workspace Visualization
-----------------------

Visualize the reachable workspace:

.. code-block:: python

    # Publish workspace boundary markers
    ros2 run miniarm_bringup workspace_visualizer

TF Frames
---------

The Mini-Arm publishes these TF frames:

.. code-block:: text

    base_link
    └── link_1 (base rotation)
        └── link_2 (shoulder)
            └── link_3 (upper arm)
                └── link_4 (forearm)
                    └── link_5 (wrist 1)
                        └── link_6 (wrist 2)
                            └── tool0 (end effector)
                                └── gripper_base
                                    ├── finger_left
                                    └── finger_right

View frames:

.. code-block:: bash

    ros2 run tf2_tools view_frames

Next Steps
----------

- :doc:`moveit` - Motion planning
- :doc:`setup` - Full ROS2 setup

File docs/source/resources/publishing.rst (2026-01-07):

Publishing to PyPI
==================

This guide explains how to publish the ``mini-arm`` package to PyPI.

Prerequisites
-------------

1. Create accounts on `PyPI <https://pypi.org>`_ and `TestPyPI <https://test.pypi.org>`_
2. Install build tools:

.. code-block:: bash

   pip install build twine

Build the Package
-----------------

From the repository root:

.. code-block:: bash

   # Clean previous builds
   rm -rf dist/ build/ src/*.egg-info

   # Build source and wheel distributions
   python -m build

This creates:

- ``dist/mini_arm-X.Y.Z.tar.gz`` (source distribution)
- ``dist/mini_arm-X.Y.Z-py3-none-any.whl`` (wheel)

Test on TestPyPI
----------------

Always test on TestPyPI first:

.. code-block:: bash

   # Upload to TestPyPI
   python -m twine upload --repository testpypi dist/*

   # Test installation
   pip install --index-url https://test.pypi.org/simple/ mini-arm

Publish to PyPI
---------------

Once verified on TestPyPI:

.. code-block:: bash

   # Upload to PyPI
   python -m twine upload dist/*

   # Verify installation
   pip install mini-arm

Using API Tokens (Recommended)
------------------------------

Instead of username/password, use API tokens:

1. Go to PyPI → Account Settings → API tokens
2. Create a token scoped to the ``mini-arm`` project
3. Create ``~/.pypirc``:

.. code-block:: ini

   [pypi]
   username = __token__
   password = pypi-YOUR-TOKEN-HERE

   [testpypi]
   username = __token__
   password = pypi-YOUR-TESTPYPI-TOKEN-HERE

Automated Publishing with GitHub Actions
----------------------------------------

Add this workflow to ``.github/workflows/publish.yml``:

.. code-block:: yaml

   name: Publish to PyPI

   on:
     release:
       types: [published]

   jobs:
     publish:
       runs-on: ubuntu-latest
       steps:
         - uses: actions/checkout@v4
         
         - name: Set up Python
           uses: actions/setup-python@v5
           with:
             python-version: '3.11'
         
         - name: Install build tools
           run: pip install build twine
         
         - name: Build package
           run: python -m build
         
         - name: Publish to PyPI
           env:
             TWINE_USERNAME: __token__
             TWINE_PASSWORD: ${{ secrets.PYPI_API_TOKEN }}
           run: python -m twine upload dist/*

Then add ``PYPI_API_TOKEN`` to your repository secrets.

Version Checklist
-----------------

Before publishing a new version:

1. ☐ Update ``src/mini_arm/version.py``
2. ☐ Update ``pyproject.toml`` version  
3. ☐ Update ROS2 ``package.xml`` versions
4. ☐ Update ``CHANGELOG.md``
5. ☐ Run tests: ``pytest tests/ -v``
6. ☐ Build docs: ``cd docs && make html``
7. ☐ Commit and tag: ``git tag -a vX.Y.Z``
8. ☐ Push: ``git push origin main --tags``
9. ☐ Create GitHub release
10. ☐ Publish to PyPI

Verifying Installation
----------------------

After publishing, verify the package works:

.. code-block:: python

   import mini_arm
   print(mini_arm.__version__)

   from mini_arm import MiniArmClient
   # Test basic functionality

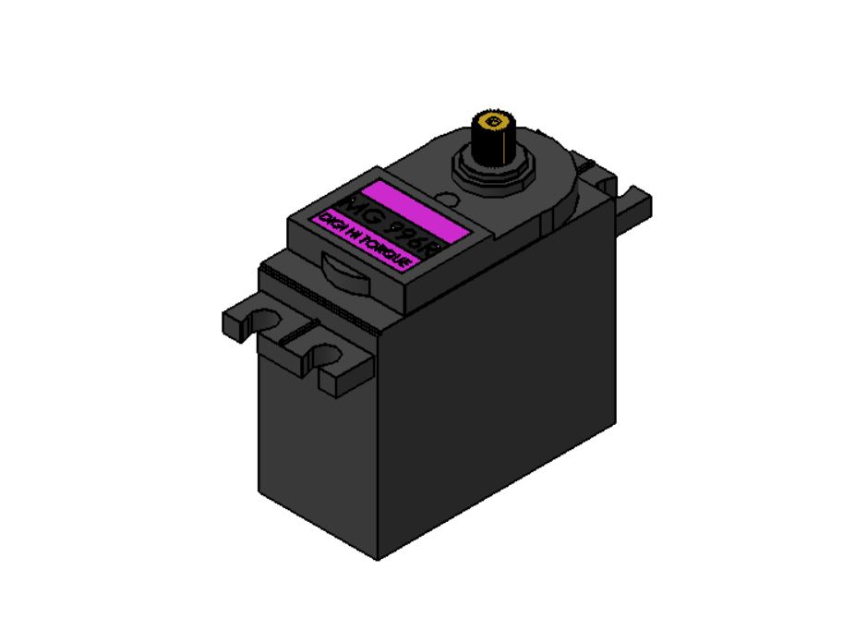
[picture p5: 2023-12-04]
hardware/cad/solidworks/servo-motor-mg-996r-1.snapshot.1/Servo Motor MG-996R.JPG

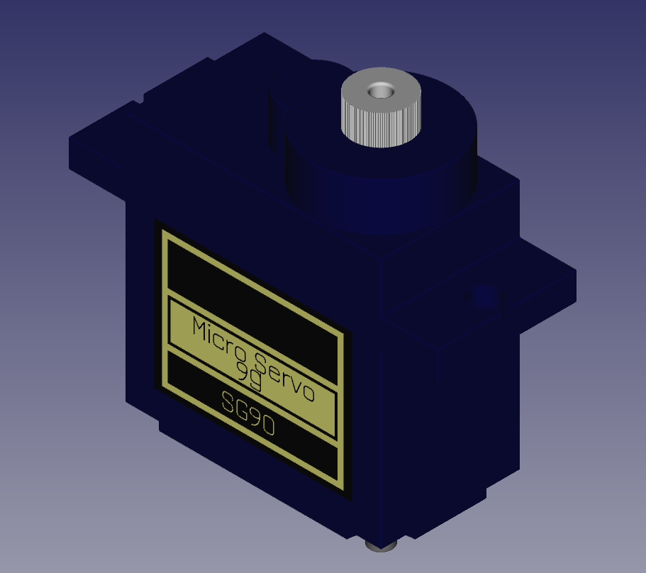
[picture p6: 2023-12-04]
hardware/cad/solidworks/micro-servo-sg90-1.snapshot.1/SG90-001.png

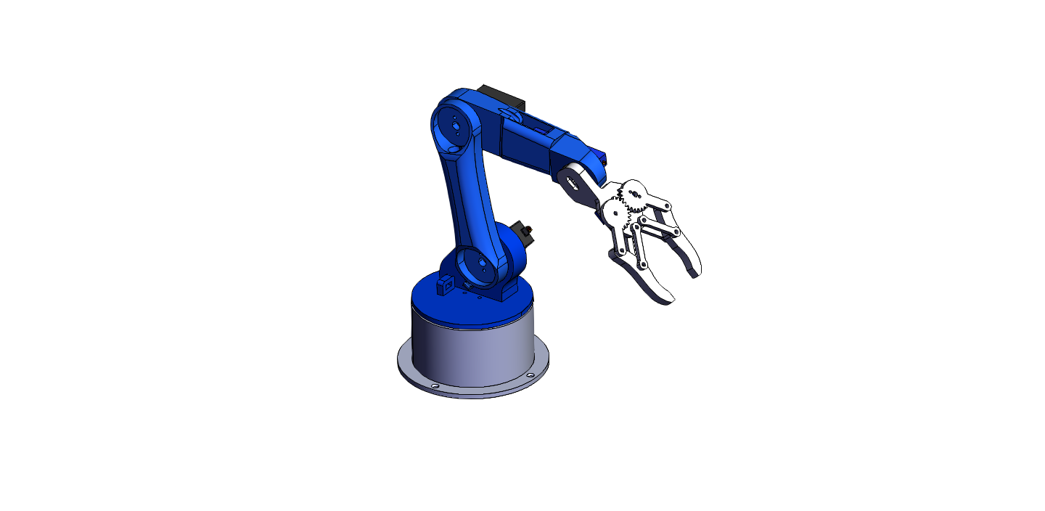
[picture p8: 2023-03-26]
assets/robotic-arm-3d-model-2023.png

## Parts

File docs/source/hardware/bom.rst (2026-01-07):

Bill of Materials
=================

Complete list of parts needed to build a Mini-Arm.

Electronics
-----------

.. list-table::
   :header-rows: 1
   :widths: 40 15 15 30

   * - Component
     - Qty
     - Price (USD)
     - Link
   * - Raspberry Pi Pico 2
     - 1
     - $5
     - `Adafruit <https://www.adafruit.com/product/5544>`_
   * - MG90S Micro Servo
     - 6
     - $18
     - `Amazon <https://amazon.com>`_
   * - SG90 Micro Servo (gripper)
     - 1
     - $3
     - `Amazon <https://amazon.com>`_
   * - PCA9685 Servo Driver
     - 1
     - $6
     - `Amazon <https://amazon.com>`_
   * - USB-C Cable
     - 1
     - $5
     - Any
   * - Jumper Wires (M-F)
     - 20
     - $4
     - `Amazon <https://amazon.com>`_
   * - 5V 3A Power Supply
     - 1
     - $8
     - `Amazon <https://amazon.com>`_

**Electronics Subtotal: ~$49**

Hardware
--------

.. list-table::
   :header-rows: 1
   :widths: 40 15 15 30

   * - Component
     - Qty
     - Price (USD)
     - Notes
   * - M2 x 8mm Screws
     - 20
     - $3
     - Pan head
   * - M2 x 12mm Screws
     - 10
     - $2
     - Pan head
   * - M2 Nuts
     - 30
     - $2
     - 
   * - M3 x 10mm Screws
     - 10
     - $2
     - Pan head
   * - M3 Nuts
     - 10
     - $2
     - 
   * - 608 Bearings (8x22x7mm)
     - 4
     - $5
     - For smooth rotation
   * - Rubber Feet
     - 4
     - $2
     - Anti-slip base

**Hardware Subtotal: ~$18**

3D Printed Parts
----------------

All parts can be printed on a standard FDM printer.

.. list-table::
   :header-rows: 1
   :widths: 50 15 20 15

   * - Part
     - Qty
     - Material
     - Time
   * - Base
     - 1
     - PLA/PETG
     - 3h
   * - Shoulder
     - 1
     - PLA/PETG
     - 2h
   * - Upper Arm
     - 1
     - PLA/PETG
     - 2h
   * - Forearm
     - 1
     - PLA/PETG
     - 1.5h
   * - Wrist
     - 1
     - PLA/PETG
     - 1h
   * - Gripper Base
     - 1
     - PLA/PETG
     - 0.5h
   * - Gripper Fingers
     - 2
     - PLA/PETG
     - 0.5h
   * - Servo Mounts
     - 6
     - PLA/PETG
     - 1h
   * - Electronics Mount
     - 1
     - PLA/PETG
     - 1h

**3D Printing: ~$15** (material cost) / **~12 hours** print time

Print settings:
- Layer height: 0.2mm
- Infill: 20%
- Supports: Yes (for some parts)
- Material: PLA recommended, PETG for durability

Download STL files from ``assets/stl/`` or `Printables <https://www.printables.com>`_.

Optional Upgrades
-----------------

.. list-table::
   :header-rows: 1
   :widths: 40 15 45

   * - Upgrade
     - Price
     - Benefit
   * - MG996R Servos
     - $30
     - Higher torque, larger payload
   * - Slip Ring
     - $8
     - Continuous base rotation
   * - Camera Mount + USB Camera
     - $15
     - Vision applications
   * - Force Sensor (gripper)
     - $10
     - Grasp force feedback
   * - Limit Switches
     - $5
     - Precise homing

Total Cost Summary
------------------

.. list-table::
   :widths: 50 50

   * - **Basic Build**
     - **~$82**
   * - Electronics
     - $49
   * - Hardware
     - $18
   * - 3D Printing (material)
     - $15
   * - 
     - 
   * - **With All Upgrades**
     - **~$150**

Next Steps
----------

- :doc:`3d_printing` - Print settings and tips
- :doc:`assembly` - Step-by-step build guide

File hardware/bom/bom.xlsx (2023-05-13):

Part | Unit Cost | Link
Microservo | $2 | https://www.amazon.com/Dorhea-Arduino-Helicopter-Airplane-Walking/dp/B07Q6JGWNV
Servo | $6 | https://www.amazon.com/4-Pack-MG996R-Torque-Digital-Helicopter/dp/B07MFK266B
PCA9685 | $8 | https://www.amazon.com/HiLetgo-PCA9685-Channel-12-Bit-Arduino/dp/B07BRS249H
Pico W | $10 | https://www.amazon.com/Generic-Raspberry-Pi-Pico-W/dp/B0B72GV3K3/ref=sr_1_3?keywords=pico+w&sr=8-3
Logic Converter | $1 | https://www.amazon.com/HiLetgo-Channels-Converter-Bi-Directional-3-3V-5V/dp/B07F7W91LC
Wires | $7 | https://www.amazon.com/Elegoo-EL-CP-004-Multicolored-Breadboard-arduino/dp/B01EV70C78
LED Rocker Switch | $1 | https://www.amazon.com/Nilight-90013L-Toggle-Control-Warranty/dp/B07T1JG6BD
DC Power Jack Socket | $2 | https://www.amazon.com/LUORNG-Threaded-Connector-Pre-soldered-Waterproof/dp/B09H5L3KN5
RGB LED | $0.1 | https://www.amazon.com/EDGELEC-Tri-Color-Multicolor-Diffused-Resistors/dp/B077XGF3YR
5V Power Supply | $6 | https://www.amazon.com/Power-Adapter-100-240V-Transformers-Supply/dp/B08722QC75
Resistors | $1 | https://www.amazon.com/MCIGICM-Values-Resistor-Assortment-Resistors/dp/B06WRQS97C
Total | $44.1

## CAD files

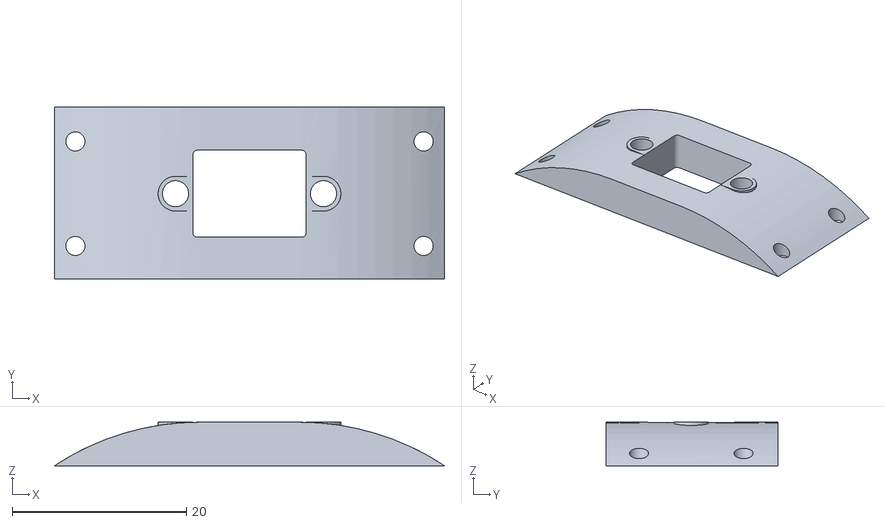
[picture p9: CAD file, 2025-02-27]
hardware/additional_models/17mm-mini-USB_connector-panel.STL
44.8 x 19.8 x 5.00

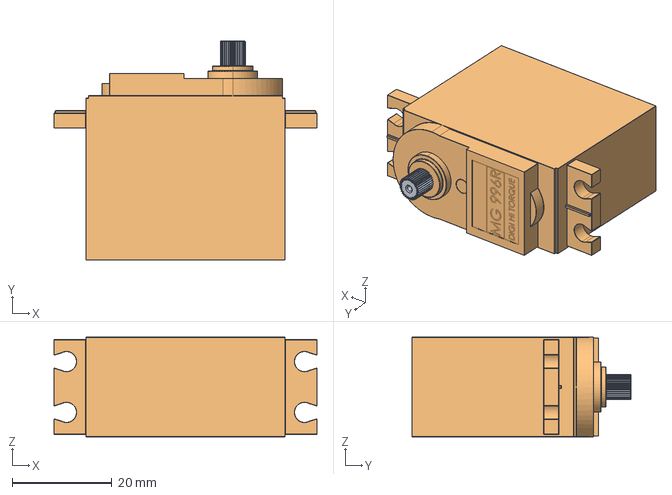
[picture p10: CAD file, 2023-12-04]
hardware/cad/solidworks/servo-motor-mg-996r-1.snapshot.1/MG-996R.stp
52.8 x 44.0 x 20.0 mm

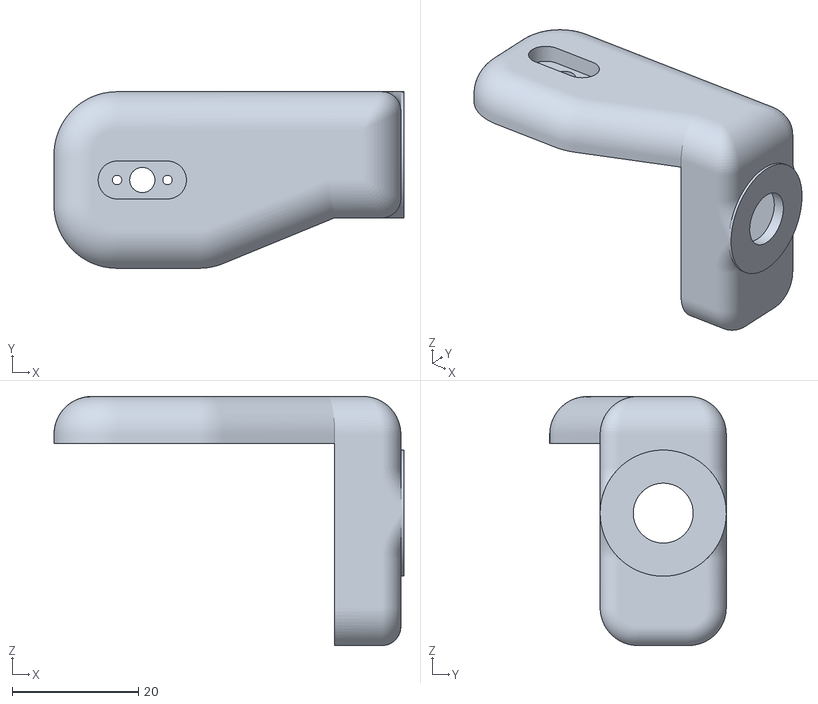
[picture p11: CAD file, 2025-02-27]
hardware/stl/link_5.STL
55.5 x 28.0 x 39.5

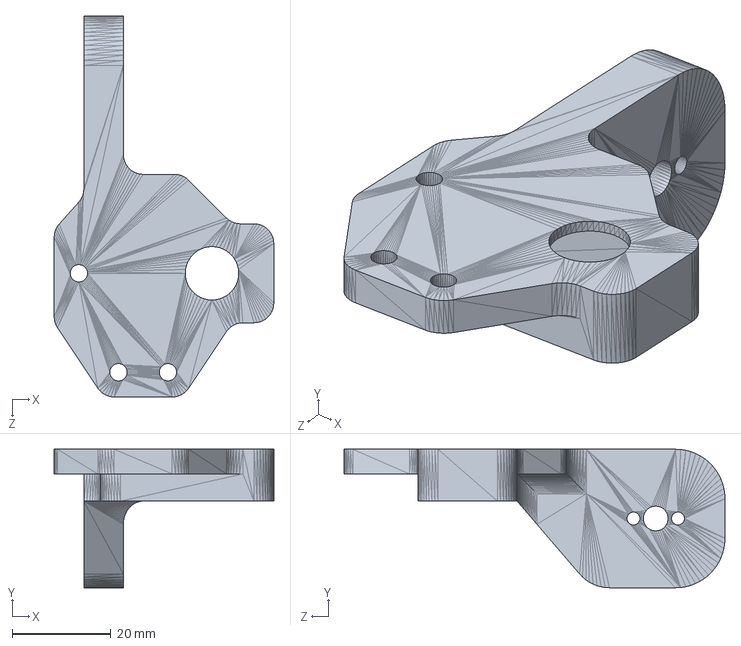
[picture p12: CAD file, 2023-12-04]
miniarm_ros/miniarm_description/solidworks/Gripper base.SLDPRT
44.4 x 28.0 x 77.0 mm

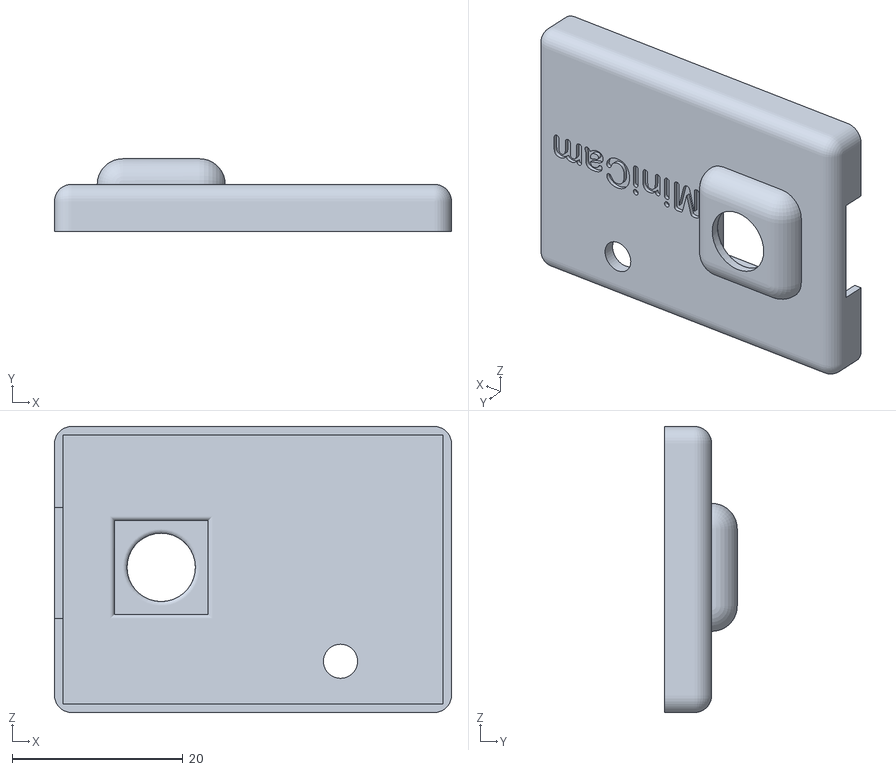
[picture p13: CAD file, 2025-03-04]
ros2/miniarm_description/meshes/esp32_case_front.STL
46.5 x 8.50 x 33.5

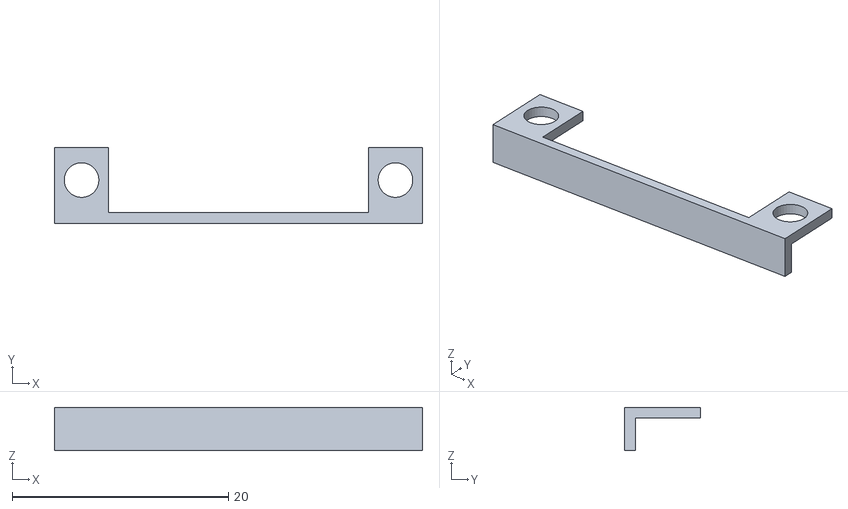
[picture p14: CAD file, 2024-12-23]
hardware/additional_models/ov7670_adapter.STL
34.0 x 7.00 x 4.00

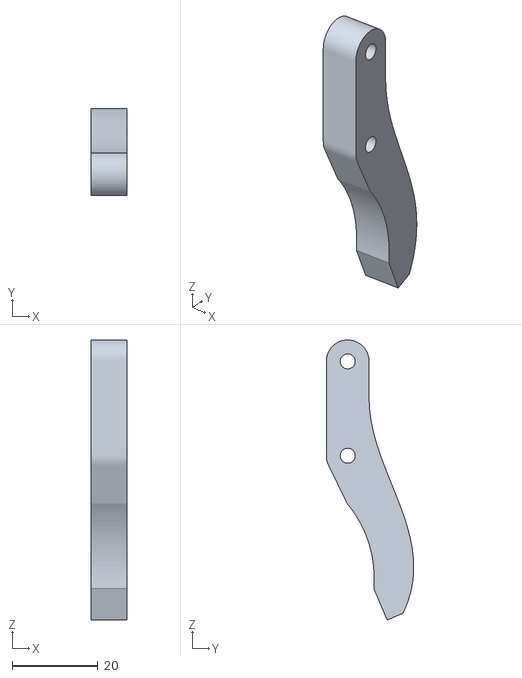
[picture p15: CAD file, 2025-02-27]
hardware/stl/gripper_finger.STL
8.50 x 20.4 x 65.3

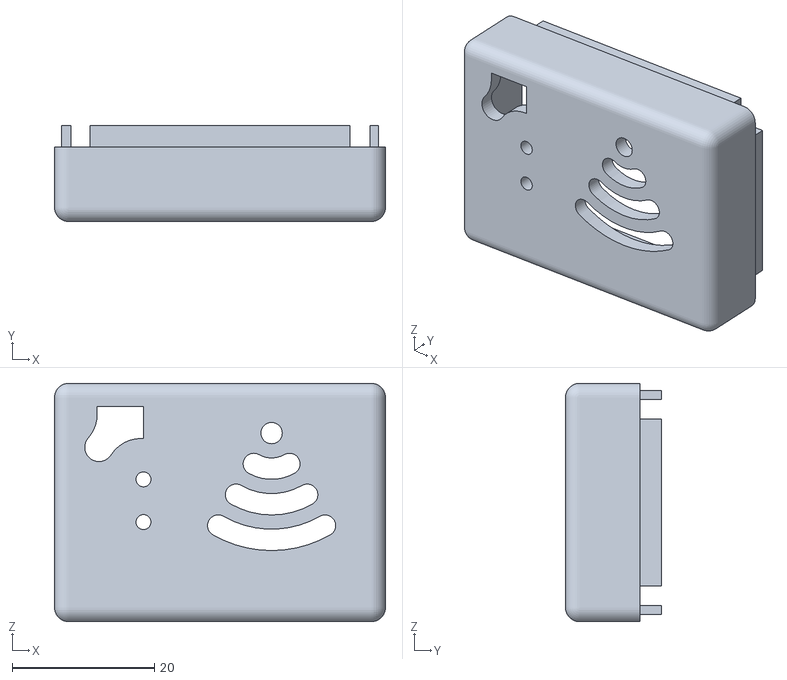
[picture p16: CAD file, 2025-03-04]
ros2/miniarm_description/meshes/esp32_case_back.STL
46.5 x 13.5 x 33.5

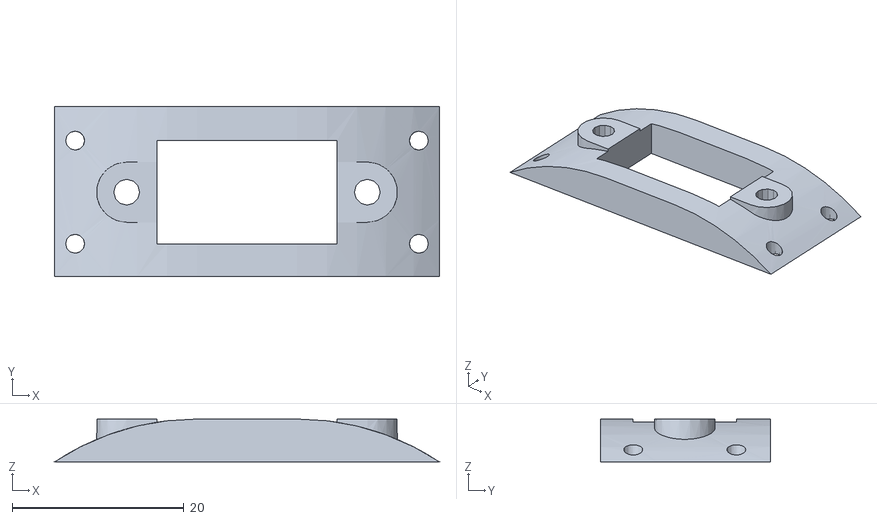
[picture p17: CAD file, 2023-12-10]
hardware/additional_models/28mm-mini-USB_connector-panel.STL
44.8 x 19.8 x 5.00

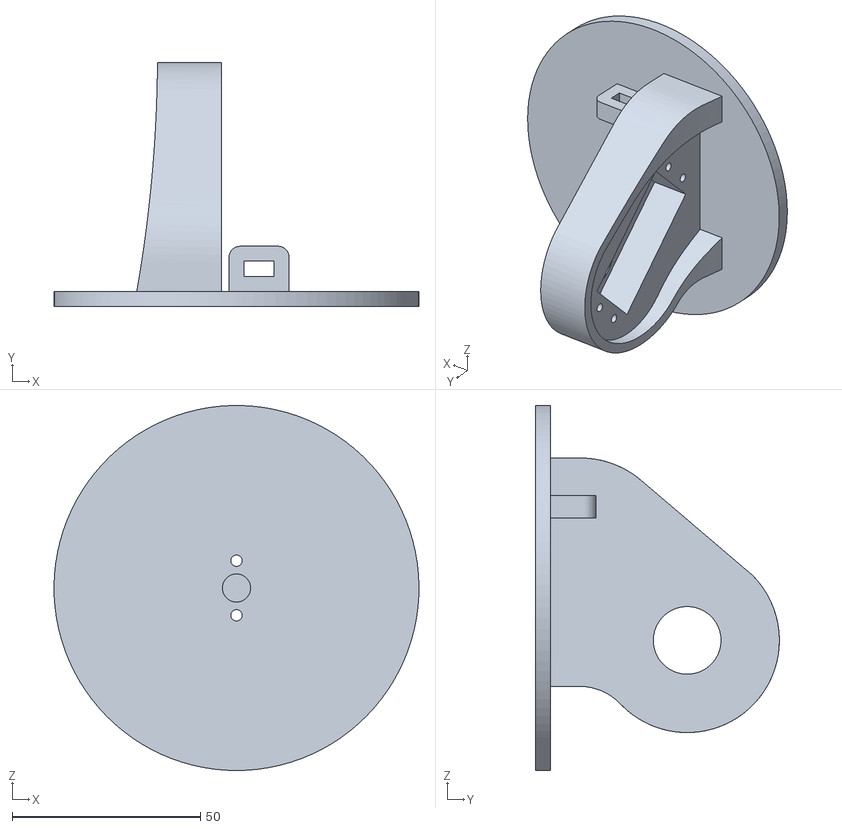
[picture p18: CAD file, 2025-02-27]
hardware/stl/link_1.STL
97.0 x 64.8 x 97.0

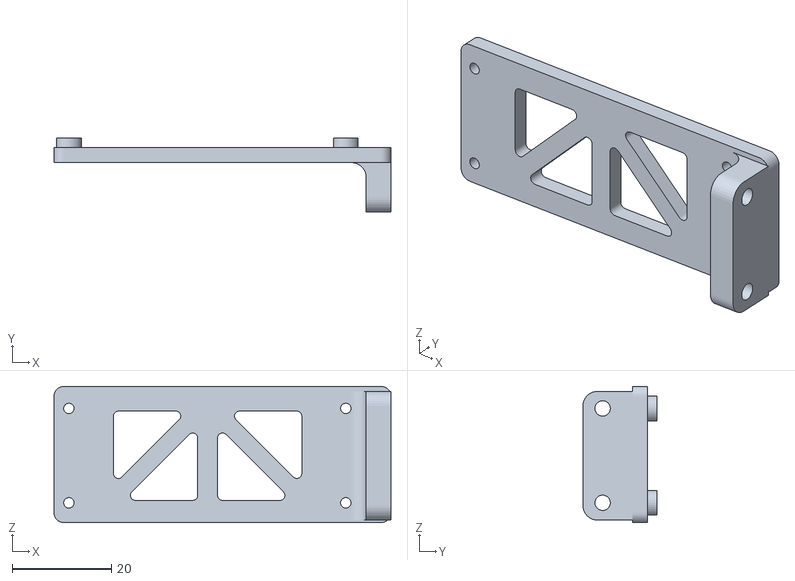
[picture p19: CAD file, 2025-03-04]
ros2/miniarm_description/meshes/PCA9685_bracket.STL
68.0 x 15.0 x 27.5

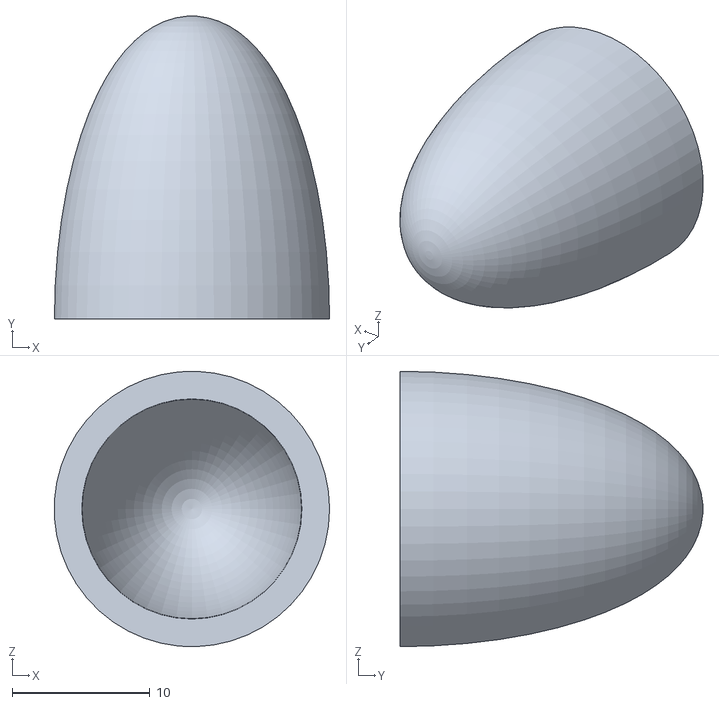
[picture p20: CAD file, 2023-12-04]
hardware/additional_models/TPU_Finger_Cap.STL
20.0 x 22.0 x 20.0

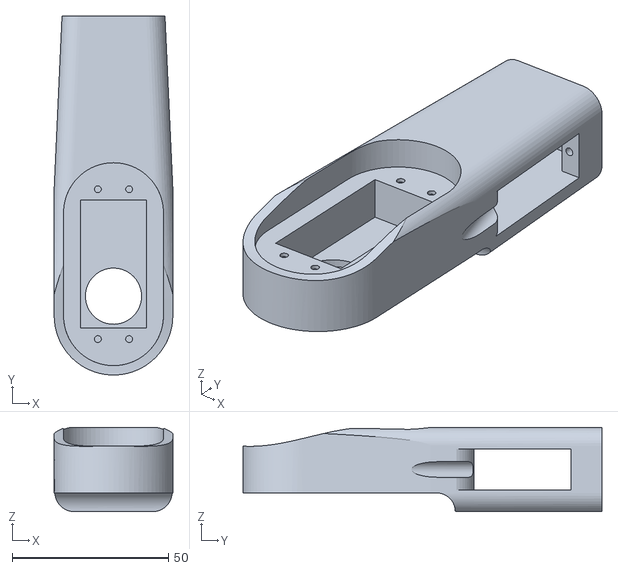
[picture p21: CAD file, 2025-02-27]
hardware/stl/link_3.STL
38.0 x 115.0 x 27.0

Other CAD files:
hardware/cad/solidworks/gripper assembly.SLDASM
hardware/cad/solidworks/esp32_case_back.SLDPRT
hardware/cad/solidworks/esp32_case_front.SLDPRT
hardware/additional_models/TPU_Thumb_Cap.obj
hardware/cad/solidworks/17mm-mini-USB_connector-panel.SLDPRT
hardware/cad/solidworks/28mm-mini-USB_connector-panel.SLDPRT
hardware/cad/solidworks/90deg_shelf_2mmhole.SLDPRT
hardware/cad/solidworks/Arm 01.SLDPRT
hardware/cad/solidworks/Arm 02 v3.SLDPRT
hardware/cad/solidworks/Arm 03.SLDPRT
hardware/cad/solidworks/Base.SLDPRT
hardware/cad/solidworks/Gripper 1.SLDPRT
hardware/cad/solidworks/PCA9685_bracket.SLDPRT
hardware/cad/solidworks/TPU_Finger_Cap.SLDPRT
hardware/cad/solidworks/TPU_Thumb_Cap.SLDPRT
hardware/cad/solidworks/Waist.SLDPRT
hardware/cad/solidworks/camera_bracket.SLDPRT
hardware/cad/solidworks/electronics deck V2.SLDPRT
hardware/cad/solidworks/electronics deck.SLDPRT
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

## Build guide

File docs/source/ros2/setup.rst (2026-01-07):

ROS2 Setup
==========

Integrate Mini-Arm with ROS2 for advanced robotics applications.

Prerequisites
-------------

- ROS2 Humble or later
- MoveIt2 (for motion planning)
- Ubuntu 22.04 (recommended)

Installation
------------

The Mini-Arm ROS2 packages include the Python client library, so everything builds together with ``colcon``.

1. Create a ROS2 workspace:

.. code-block:: bash

    mkdir -p ~/miniarm_ws/src
    cd ~/miniarm_ws/src

2. Clone the Mini-Arm repository and symlink packages:

.. code-block:: bash

    git clone https://github.com/Jshulgach/Mini-Arm.git
    ln -s Mini-Arm/ros2/* .

3. Install ROS dependencies:

.. code-block:: bash

    cd ~/miniarm_ws
    rosdep install --from-paths src --ignore-src -r -y

4. Build all packages:

.. code-block:: bash

    colcon build --symlink-install
    source install/setup.bash

This builds **all** Mini-Arm packages:

- ``miniarm_core`` - Python client library (MiniArmClient)
- ``miniarm_description`` - URDF and meshes
- ``miniarm_moveit_config`` - MoveIt2 configuration
- ``miniarm_servo`` - Real-time servo control

Alternative: vcstool
--------------------

For teams or CI/CD, create a ``miniarm.repos`` file:

.. code-block:: yaml

    repositories:
      Mini-Arm:
        type: git
        url: https://github.com/Jshulgach/Mini-Arm.git
        version: v0.4.0

Then:

.. code-block:: bash

    cd ~/miniarm_ws/src
    vcs import < miniarm.repos
    ln -s Mini-Arm/ros2/* .
    cd ~/miniarm_ws
    colcon build

Package Structure
-----------------

.. code-block:: text

    ros2/
    ├── miniarm_core/            # Python client (ament_python)
    │   └── miniarm_core/
    │       ├── client.py        # MiniArmClient class
    │       └── __main__.py      # CLI
    ├── miniarm_description/     # URDF, meshes
    ├── miniarm_moveit_config/   # MoveIt2 configuration
    └── miniarm_servo/           # Real-time control

Using miniarm_core in ROS2 Nodes
--------------------------------

After building, you can import the client in your ROS2 Python nodes:

.. code-block:: python

    from miniarm_core import MiniArmClient
    
    client = MiniArmClient(port='/dev/ttyACM0')
    client.home()
    client.set_pose(0.135, 0.0, 0.22)

Launching
---------

**View robot in RViz:**

.. code-block:: bash

    ros2 launch miniarm_servo show_robot.launch.py

Topics
------

**Published:**

- ``/joint_states`` (sensor_msgs/JointState) - Current joint positions
- ``/miniarm/end_effector_pose`` (geometry_msgs/PoseStamped) - TCP pose

**Subscribed:**

- ``/miniarm/joint_command`` (std_msgs/Float64MultiArray) - Joint position commands
- ``/miniarm/gripper_command`` (std_msgs/Float64) - Gripper position (0-1)

Services
--------

- ``/miniarm/home`` - Move to home position
- ``/miniarm/enable`` - Enable servos
- ``/miniarm/disable`` - Disable servos (freedrive)

Parameters
----------

Configure via ``miniarm_bringup/config/miniarm_params.yaml``:

.. code-block:: yaml

    miniarm:
      ros__parameters:
        serial_port: "/dev/ttyACM0"
        baudrate: 115200
        publish_rate: 50.0
        joint_limits:
          - [-180.0, 180.0]  # base
          - [-90.0, 90.0]    # shoulder
          - [-135.0, 135.0]  # elbow
          - [-180.0, 180.0]  # wrist_1
          - [-90.0, 90.0]    # wrist_2
          - [-180.0, 180.0]  # wrist_3

Example: ROS2 Control
---------------------

.. code-block:: python

    import rclpy
    from rclpy.node import Node
    from std_msgs.msg import Float64MultiArray

    class MiniArmController(Node):
        def __init__(self):
            super().__init__('miniarm_controller')
            self.publisher = self.create_publisher(
                Float64MultiArray,
                '/miniarm/joint_command',
                10
            )

        def send_joints(self, angles):
            msg = Float64MultiArray()
            msg.data = angles
            self.publisher.publish(msg)

    def main():
        rclpy.init()
        controller = MiniArmController()
        
        # Move to position
        controller.send_joints([0.0, -0.5, 1.0, 0.0, 0.5, 0.0])
        
        rclpy.spin(controller)
        rclpy.shutdown()

Next Steps
----------

- :doc:`visualization` - RViz setup
- :doc:`moveit` - Motion planning with MoveIt2

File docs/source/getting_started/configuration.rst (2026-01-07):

Configuration
=============

This guide covers configuration options for the Mini-Arm client library.

Serial Port Configuration
-------------------------

Auto-detect (default):

.. code-block:: python

    arm = MiniArm()  # Automatically finds the Pico

Specify port explicitly:

.. code-block:: python

    # Windows
    arm = MiniArm(port="COM3")

    # Linux
    arm = MiniArm(port="/dev/ttyACM0")

    # macOS
    arm = MiniArm(port="/dev/tty.usbmodem1234")

Connection Parameters
---------------------

.. code-block:: python

    arm = MiniArm(
        port="COM3",
        baudrate=115200,      # Communication speed
        timeout=1.0,          # Read timeout in seconds
        auto_connect=True,    # Connect immediately on creation
    )

Robot Configuration
-------------------

Create a configuration file ``mini_arm_config.yaml``:

.. code-block:: yaml

    # Mini-Arm Configuration
    robot:
      name: "my-mini-arm"
      serial_port: "COM3"
      baudrate: 115200

    # Joint configuration
    joints:
      - name: base
        min_angle: -180
        max_angle: 180
        home_angle: 0
        speed: 100  # degrees per second

      - name: shoulder
        min_angle: -90
        max_angle: 90
        home_angle: 0
        speed: 80

      # ... additional joints

    # Kinematics
    kinematics:
      dh_params:
        - [0, 0, 50, 0]      # Link 1: [a, alpha, d, theta_offset]
        - [0, -90, 0, 0]     # Link 2
        - [93, 0, 0, 0]      # Link 3
        - [83, 0, 0, 0]      # Link 4
        - [0, -90, 0, 0]     # Link 5
        - [0, 0, 50, 0]      # Link 6

    # Safety limits
    safety:
      max_velocity: 180      # deg/s
      max_acceleration: 360  # deg/s²
      collision_check: true

Load configuration:

.. code-block:: python

    arm = MiniArm.from_config("mini_arm_config.yaml")

Logging
-------

Enable debug logging:

.. code-block:: python

    import logging
    logging.basicConfig(level=logging.DEBUG)

    arm = MiniArm(debug=True)

Environment Variables
---------------------

.. code-block:: bash

    # Set default serial port
    export MINIARM_PORT=/dev/ttyACM0

    # Enable verbose output
    export MINIARM_DEBUG=1

    # Set configuration file path
    export MINIARM_CONFIG=/path/to/config.yaml

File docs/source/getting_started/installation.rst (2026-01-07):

Installation
============

This guide will help you install the Mini-Arm Python client library and set up your development environment.

Requirements
------------

- Python 3.8 or higher
- A Mini-Arm robot (or you can use the simulator)
- USB cable for connecting to the Pico

Quick Install
-------------

Install directly from GitHub:

.. code-block:: bash

    pip install git+https://github.com/Jshulgach/Mini-Arm.git

Or clone and install in development mode:

.. code-block:: bash

    git clone https://github.com/Jshulgach/Mini-Arm.git
    cd Mini-Arm
    pip install -e .

Dependencies
------------

The following packages will be installed automatically:

- ``pyserial`` - Serial communication with the Pico
- ``numpy`` - Mathematical operations
- ``scipy`` - Trajectory interpolation

Optional Dependencies
---------------------

For visualization and advanced features:

.. code-block:: bash

    # For 3D visualization
    pip install matplotlib

    # For Xbox controller support
    pip install pygame

    # For ROS2 integration
    # See the ROS2 Setup guide

Firmware Installation
---------------------

Your Mini-Arm's Raspberry Pi Pico needs to be flashed with the CircuitPython firmware:

1. Download the latest CircuitPython UF2 from `circuitpython.org <https://circuitpython.org/board/raspberry_pi_pico/>`_
2. Hold the BOOTSEL button on the Pico and connect USB
3. Drag the UF2 file to the RPI-RP2 drive
4. Copy the contents of ``pico/`` folder to the CIRCUITPY drive

Verifying Installation
----------------------

Test your installation:

.. code-block:: python

    from mini_arm import MiniArm

    # Connect to Mini-Arm
    arm = MiniArm()
    arm.connect()

    # Check connection
    print(f"Connected: {arm.is_connected}")
    print(f"Firmware version: {arm.firmware_version}")

    # Move to home position
    arm.home()

Next Steps
----------

- :doc:`quickstart` - Your first Mini-Arm program
- :doc:`configuration` - Configure serial port and settings

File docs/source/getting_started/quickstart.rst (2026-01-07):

Quickstart Guide
================

This guide will have you controlling your Mini-Arm in under 5 minutes.

Basic Control
-------------

.. code-block:: python

    from mini_arm import MiniArm

    # Create and connect
    arm = MiniArm(port="COM3")  # Adjust port for your system
    arm.connect()

    # Move to home position
    arm.home()

    # Move individual joints (angles in degrees)
    arm.set_joint(0, 45)   # Base rotation
    arm.set_joint(1, -30)  # Shoulder
    arm.set_joint(2, 60)   # Elbow

    # Move all joints at once
    arm.set_joints([0, -45, 90, 0, 45, 0])

Cartesian Control
-----------------

Use the built-in inverse kinematics solver:

.. code-block:: python

    # Move end-effector to XYZ position (in mm)
    arm.move_to(x=100, y=0, z=150)

    # Move with orientation (roll, pitch, yaw in degrees)
    arm.move_to(x=100, y=50, z=100, roll=0, pitch=90, yaw=0)

    # Get current end-effector position
    pos = arm.get_position()
    print(f"Position: X={pos.x}, Y={pos.y}, Z={pos.z}")

Smooth Trajectories
-------------------

.. code-block:: python

    # Define waypoints
    waypoints = [
        [0, 0, 0, 0, 0, 0],      # Home
        [45, -30, 60, 0, 30, 0],  # Point A
        [-45, -30, 60, 0, 30, 0], # Point B
        [0, 0, 0, 0, 0, 0],       # Home
    ]

    # Execute trajectory with smooth interpolation
    arm.execute_trajectory(waypoints, duration=5.0)

Gripper Control
---------------

.. code-block:: python

    # Open and close gripper
    arm.gripper_open()
    arm.gripper_close()

    # Set specific gripper position (0-100%)
    arm.gripper_set(50)

Safety & Limits
---------------

The Mini-Arm has built-in joint limits to prevent self-collision:

.. list-table:: Joint Limits
   :header-rows: 1

   * - Joint
     - Min (°)
     - Max (°)
   * - Base (J0)
     - -180
     - 180
   * - Shoulder (J1)
     - -90
     - 90
   * - Elbow (J2)
     - -135
     - 135
   * - Wrist Roll (J3)
     - -180
     - 180
   * - Wrist Pitch (J4)
     - -90
     - 90
   * - Wrist Yaw (J5)
     - -180
     - 180

Next Steps
----------

- :doc:`/tutorials/basic_control` - Detailed control examples
- :doc:`/tutorials/trajectories` - Advanced trajectory planning
- :doc:`/hardware/assembly` - Build your own Mini-Arm

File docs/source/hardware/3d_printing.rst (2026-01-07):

3D Printing Guide
=================

Detailed instructions for printing Mini-Arm components.

Recommended Settings
--------------------

**General Settings:**

.. list-table::
   :widths: 30 70

   * - Layer Height
     - 0.2mm (0.16mm for fine details)
   * - Nozzle
     - 0.4mm standard
   * - Infill
     - 20% (gyroid or grid)
   * - Wall Count
     - 3-4 perimeters
   * - Top/Bottom Layers
     - 4 layers
   * - Support
     - Yes, where needed
   * - Bed Adhesion
     - Brim (5mm)

**Material Recommendations:**

- **PLA** - Easy to print, sufficient for most uses
- **PETG** - Better durability, slight flexibility
- **ABS** - Heat resistant, requires enclosure

Part-by-Part Settings
---------------------

Base
^^^^

.. code-block:: text

    Orientation: Flat (large face down)
    Supports: No
    Infill: 30% (structural)
    Notes: Use brim for adhesion

Shoulder & Upper Arm
^^^^^^^^^^^^^^^^^^^^

.. code-block:: text

    Orientation: On side (bearing holes vertical)
    Supports: Yes (touching buildplate only)
    Infill: 20%
    Notes: Critical for bearing fit

Forearm & Wrist
^^^^^^^^^^^^^^^

.. code-block:: text

    Orientation: Servo mount facing up
    Supports: Yes
    Infill: 20%
    Notes: Check servo horn clearance

Gripper
^^^^^^^

.. code-block:: text

    Orientation: Flat
    Supports: Minimal
    Infill: 15%
    Notes: Print fingers separately

Post-Processing
---------------

1. **Remove Supports** - Use flush cutters, then sand
2. **Test Fit Bearings** - May need light sanding
3. **Thread Brass Inserts** (optional) - Use soldering iron
4. **Chamfer Edges** - Utility knife for cleaner look

Troubleshooting
---------------

**Parts don't fit together:**

- Check printer calibration (print a calibration cube)
- Adjust horizontal expansion in slicer (-0.1 to -0.2mm)
- Light sanding on tight fits

**Weak/brittle parts:**

- Increase wall count to 4+
- Increase infill to 30%
- Check for under-extrusion

**Warping:**

- Use heated bed (60°C for PLA)
- Ensure proper first layer adhesion
- Use enclosure for ABS

File Downloads
--------------

STL files are available in the repository:

.. code-block:: bash

    Mini-Arm/assets/stl/
    ├── base.stl
    ├── shoulder.stl
    ├── upper_arm.stl
    ├── forearm.stl
    ├── wrist.stl
    ├── gripper_base.stl
    ├── gripper_finger_left.stl
    ├── gripper_finger_right.stl
    └── electronics_mount.stl

Or download from `Printables <https://www.printables.com>`_ (link TBD).

STEP files for modifications are in ``assets/cad/``.

Next Steps
----------

- :doc:`assembly` - Build your Mini-Arm
- :doc:`wiring` - Electronics installation

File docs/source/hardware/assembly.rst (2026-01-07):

Assembly Guide
==============

Step-by-step instructions to build your Mini-Arm.

Before You Start
----------------

**Required Tools:**

- Phillips screwdriver (small)
- Hex keys (2mm, 2.5mm)
- Needle-nose pliers
- Wire strippers
- Soldering iron (optional, for upgrades)

**Verify Parts:**

Check all 3D printed parts and hardware against the :doc:`bom`.

Step 1: Base Assembly
---------------------



1. Insert 608 bearing into the base plate center hole
2. Attach base servo (J0) using M2 x 8mm screws
3. Press-fit the servo horn into the rotating base plate
4. Connect base plate to servo with the servo horn screw

Step 2: Shoulder Joint
----------------------



1. Install shoulder servo (J1) into the shoulder mount
2. Secure with M2 x 8mm screws
3. Attach the shoulder bracket to the base plate
4. Install 608 bearing for support

Step 3: Upper Arm
-----------------



1. Mount elbow servo (J2) in the upper arm housing
2. Secure with M2 x 8mm screws
3. Connect upper arm to shoulder servo horn
4. Ensure smooth rotation - adjust if binding

Step 4: Forearm
---------------



1. Install wrist servos (J3, J4) in forearm housing
2. Route servo wires through the forearm channel
3. Connect forearm to elbow servo horn
4. Test range of motion

Step 5: Wrist & Gripper
-----------------------



1. Mount wrist yaw servo (J5) in wrist housing
2. Attach gripper servo (J6) to gripper base
3. Install gripper fingers with M2 x 12mm screws
4. Connect wrist assembly to forearm

Step 6: Electronics
-------------------



1. Mount Raspberry Pi Pico to electronics bracket
2. Mount PCA9685 servo driver next to Pico
3. Connect I2C wires:
   - Pico GP0 (SDA) → PCA9685 SDA
   - Pico GP1 (SCL) → PCA9685 SCL
   - Pico 3.3V → PCA9685 VCC
   - Pico GND → PCA9685 GND

4. Connect servo wires to PCA9685 channels 0-6
5. Connect 5V power supply to PCA9685 V+ terminal

Wiring Diagram
--------------

.. code-block:: text

                    ┌─────────────────┐
                    │  Raspberry Pi   │
                    │     Pico 2      │
                    │                 │
                    │ GP0 (SDA) ──────┼──────┐
                    │ GP1 (SCL) ──────┼────┐ │
                    │ 3.3V ───────────┼──┐ │ │
                    │ GND ────────────┼┐ │ │ │
                    └─────────────────┘│ │ │ │
                                       │ │ │ │
    ┌──────────────────────────────────┼─┼─┼─┼──┐
    │  PCA9685 Servo Driver            │ │ │ │  │
    │                                  │ │ │ │  │
    │  GND ────────────────────────────┘ │ │ │  │
    │  VCC ──────────────────────────────┘ │ │  │
    │  SCL ────────────────────────────────┘ │  │
    │  SDA ──────────────────────────────────┘  │
    │                                           │
    │  CH0 ─── J0 (Base)                        │
    │  CH1 ─── J1 (Shoulder)                    │
    │  CH2 ─── J2 (Elbow)                       │
    │  CH3 ─── J3 (Wrist Roll)                  │
    │  CH4 ─── J4 (Wrist Pitch)                 │
    │  CH5 ─── J5 (Wrist Yaw)                   │
    │  CH6 ─── Gripper                          │
    │                                           │
    │  V+ ──── 5V Power Supply (+)              │
    │  GND ─── 5V Power Supply (-)              │
    └───────────────────────────────────────────┘

Step 7: Cable Management
------------------------

1. Bundle servo wires with cable ties
2. Route wires along the arm structure
3. Leave slack at each joint for full range of motion
4. Secure electronics mount to the base

Step 8: Firmware Installation
-----------------------------

1. Connect Pico via USB while holding BOOTSEL button
2. Drag CircuitPython UF2 to the RPI-RP2 drive
3. Copy contents of ``pico/`` folder to CIRCUITPY drive:

.. code-block:: text

    CIRCUITPY/
    ├── code.py
    ├── lib/
    │   ├── adafruit_pca9685.mpy
    │   ├── adafruit_motor/
    │   └── mini_arm/
    └── config.json

Step 9: Calibration
-------------------

Run the calibration script:

.. code-block:: bash

    python -m mini_arm.calibrate

This will:

1. Move each joint to find limits
2. Set servo center positions
3. Save calibration to the Pico

Step 10: Final Test
-------------------

.. code-block:: python

    from mini_arm import MiniArm

    arm = MiniArm()
    arm.connect()

    # Test each joint
    for i in range(6):
        print(f"Testing joint {i}")
        arm.set_joint(i, 30)
        time.sleep(0.5)
        arm.set_joint(i, -30)
        time.sleep(0.5)
        arm.set_joint(i, 0)

    # Test gripper
    arm.gripper_open()
    arm.gripper_close()

    # Home position
    arm.home()

    print("Assembly complete! 🎉")

Troubleshooting
---------------

**Servo not moving:**

- Check wiring connections
- Verify power supply is connected
- Check servo channel assignment

**Jerky motion:**

- Reduce speed: ``arm.set_speed(30)``
- Check for mechanical binding
- Lubricate bearings if needed

**Overheating servos:**

- Don't leave servos under continuous load
- Check for over-tightened screws
- Consider upgrading to higher-torque servos

Next Steps
----------

- :doc:`wiring` - Detailed wiring guide
- :doc:`/getting_started/quickstart` - Start programming
- :doc:`/tutorials/basic_control` - Control tutorials

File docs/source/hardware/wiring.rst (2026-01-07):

Wiring Guide
============

Detailed wiring instructions for Mini-Arm electronics.

Components
----------

- Raspberry Pi Pico 2
- PCA9685 16-channel PWM driver
- 7x Micro servos (6 joints + gripper)
- 5V 3A Power supply
- Jumper wires

Pin Connections
---------------

Pico to PCA9685
^^^^^^^^^^^^^^^

.. list-table::
   :header-rows: 1
   :widths: 30 30 40

   * - Pico Pin
     - PCA9685 Pin
     - Function
   * - GP0
     - SDA
     - I2C Data
   * - GP1
     - SCL
     - I2C Clock
   * - 3V3 (OUT)
     - VCC
     - Logic power
   * - GND
     - GND
     - Ground

PCA9685 to Servos
^^^^^^^^^^^^^^^^^

.. list-table::
   :header-rows: 1
   :widths: 20 30 50

   * - Channel
     - Joint
     - Wire Colors (typical)
   * - 0
     - Base (J0)
     - Brown=GND, Red=5V, Orange=Signal
   * - 1
     - Shoulder (J1)
     - Same
   * - 2
     - Elbow (J2)
     - Same
   * - 3
     - Wrist Roll (J3)
     - Same
   * - 4
     - Wrist Pitch (J4)
     - Same
   * - 5
     - Wrist Yaw (J5)
     - Same
   * - 6
     - Gripper
     - Same

Power Connections
^^^^^^^^^^^^^^^^^

.. warning::

    The PCA9685 has TWO power inputs:
    
    - **VCC** (3.3V-5V) - Logic power from Pico
    - **V+** (5-6V) - Servo power from external supply
    
    DO NOT power servos from Pico's 5V pin!

External power supply connections:

.. code-block:: text

    5V Power Supply (+) ──── PCA9685 V+ terminal
    5V Power Supply (-) ──── PCA9685 GND terminal

Wiring Diagram
--------------

.. code-block:: text

                           USB
                            │
    ┌───────────────────────┴───────────────────────┐
    │              Raspberry Pi Pico 2              │
    │                                               │
    │  GP0  ●──────────────────────────────┐        │
    │  GP1  ●────────────────────────────┐ │        │
    │  3V3  ●──────────────────────────┐ │ │        │
    │  GND  ●────────────────────────┐ │ │ │        │
    │                                │ │ │ │        │
    └────────────────────────────────┼─┼─┼─┼────────┘
                                     │ │ │ │
         ┌───────────────────────────┼─┼─┼─┼────────┐
         │  PCA9685 PWM Driver       │ │ │ │        │
         │                           │ │ │ │        │
         │  GND ─────────────────────┘ │ │ │        │
         │  VCC ───────────────────────┘ │ │        │
         │  SCL ─────────────────────────┘ │        │
         │  SDA ───────────────────────────┘        │
         │                                          │
         │  ┌─────┬─────┬─────┬─────┬─────┬─────┬─────┐
         │  │ CH0 │ CH1 │ CH2 │ CH3 │ CH4 │ CH5 │ CH6 │
         │  └──┬──┴──┬──┴──┬──┴──┬──┴──┬──┴──┬──┴──┬──┘
         │     │     │     │     │     │     │     │
         │     │     │     │     │     │     │     │
         │  V+ ────────────────────────────────────── 5V+
         │  GND ───────────────────────────────────── 5V-
         └─────────────────────────────────────────────┘
               │     │     │     │     │     │     │
               ▼     ▼     ▼     ▼     ▼     ▼     ▼
              J0    J1    J2    J3    J4    J5  Gripper
             Base  Shldr Elbow  W.R   W.P   W.Y

Servo Wire Routing
------------------

Route wires along the arm to prevent tangling:

1. **Base to Shoulder** - Route through the rotating base center
2. **Shoulder to Elbow** - Along upper arm exterior
3. **Elbow to Wrist** - Through forearm channel
4. **Wrist to Gripper** - Direct connection

Use these techniques:

- Cable ties every 2-3 inches
- Leave 1-2" slack at each joint
- Use cable wrap or braided sleeve
- Secure to arm with hot glue (removable with isopropyl alcohol)

Testing Connections
-------------------

After wiring, run the connection test:

.. code-block:: python

    from mini_arm import MiniArm

    arm = MiniArm()
    
    # Test I2C connection
    if arm.test_connection():
        print("✓ PCA9685 detected")
    else:
        print("✗ Check I2C wiring")

    # Test each servo
    arm.connect()
    for i in range(7):
        print(f"Testing channel {i}...")
        arm.set_servo_raw(i, 1500)  # Center position
        input("Press Enter for next...")

Common Wiring Issues
--------------------

**"No I2C device found"**

- Check SDA/SCL connections (GP0/GP1)
- Verify VCC is connected (3.3V)
- Check for loose connections

**Servo doesn't move**

- Check V+ power is connected
- Verify correct channel
- Test servo with known-good signal

**Erratic servo behavior**

- Power supply insufficient (need 3A for all servos)
- Ground loop - ensure common ground
- Interference - keep servo wires away from power

**Servos twitch at startup**

- Normal - servos initialize to last position
- Add capacitor (100-1000µF) on V+ line

Optional: Power Monitoring
--------------------------

Add current sensing for safety:

.. code-block:: python

    # Using INA219 current sensor
    from adafruit_ina219 import INA219

    ina = INA219(i2c)
    
    current = ina.current  # mA
    if current > 2500:
        print("Warning: High current draw!")
        arm.emergency_stop()

Next Steps
----------

- :doc:`assembly` - Complete build guide
- :doc:`/getting_started/installation` - Install firmware

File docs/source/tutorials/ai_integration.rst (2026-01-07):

AI Integration
==============

Integrate Mini-Arm with LLMs and AI systems for intelligent, natural language control.

Natural Language Commands
-------------------------

Use an LLM to interpret commands and generate robot actions:

.. code-block:: python

    from mini_arm import MiniArm
    from openai import OpenAI

    arm = MiniArm()
    arm.connect()

    client = OpenAI()

    SYSTEM_PROMPT = """
    You are a robot arm controller. Given a natural language command,
    output a JSON object with the action to perform.

    Available actions:
    - {"action": "move_to", "x": float, "y": float, "z": float}
    - {"action": "set_joints", "angles": [j0, j1, j2, j3, j4, j5]}
    - {"action": "gripper", "state": "open" | "close" | float(0-100)}
    - {"action": "home"}
    - {"action": "wave"}

    The robot workspace is approximately:
    - X: -150 to 150 mm
    - Y: -150 to 150 mm
    - Z: 0 to 200 mm

    Respond with ONLY the JSON object.
    """

    def execute_command(text: str):
        response = client.chat.completions.create(
            model="gpt-4o-mini",
            messages=[
                {"role": "system", "content": SYSTEM_PROMPT},
                {"role": "user", "content": text}
            ],
            response_format={"type": "json_object"}
        )

        action = json.loads(response.choices[0].message.content)

        if action["action"] == "move_to":
            arm.move_to(x=action["x"], y=action["y"], z=action["z"])
        elif action["action"] == "set_joints":
            arm.set_joints(action["angles"])
        elif action["action"] == "gripper":
            if action["state"] == "open":
                arm.gripper_open()
            elif action["state"] == "close":
                arm.gripper_close()
            else:
                arm.gripper_set(action["state"])
        elif action["action"] == "home":
            arm.home()
        elif action["action"] == "wave":
            wave_motion()

    # Interactive loop
    while True:
        command = input("Command: ")
        if command.lower() == "quit":
            break
        execute_command(command)

Voice Control
-------------

Add speech recognition for hands-free operation:

.. code-block:: python

    import speech_recognition as sr

    recognizer = sr.Recognizer()
    mic = sr.Microphone()

    print("Say a command...")

    with mic as source:
        recognizer.adjust_for_ambient_noise(source)
        audio = recognizer.listen(source)

    try:
        text = recognizer.recognize_whisper(audio)
        print(f"Heard: {text}")
        execute_command(text)
    except sr.UnknownValueError:
        print("Could not understand audio")

Vision-Language Integration
---------------------------

Combine object detection with LLM reasoning:

.. code-block:: python

    from mini_arm.vision import Camera, detect_objects

    camera = Camera()

    def find_and_pick(object_description: str):
        # Capture image
        frame = camera.capture()

        # Use vision model to find object
        detections = detect_objects(
            frame,
            prompt=object_description,
            model="grounding-dino"
        )

        if not detections:
            print(f"Could not find: {object_description}")
            return False

        # Get object position in robot frame
        obj = detections[0]
        robot_pos = camera.pixel_to_robot(obj.center, obj.depth)

        # Pick the object
        arm.move_to(x=robot_pos.x, y=robot_pos.y, z=robot_pos.z + 50)
        arm.gripper_open()
        arm.move_to(z=robot_pos.z)
        arm.gripper_close()
        arm.move_to(z=robot_pos.z + 50)

        return True

    # Example usage
    find_and_pick("the red apple on the left")

Agentic Control
---------------

Create an autonomous agent that can plan and execute complex tasks:

.. code-block:: python

    from langchain.agents import create_tool_calling_agent
    from langchain_openai import ChatOpenAI
    from langchain.tools import tool

    @tool
    def move_arm(x: float, y: float, z: float) -> str:
        """Move the robot arm to XYZ position in millimeters."""
        arm.move_to(x=x, y=y, z=z)
        return f"Moved to ({x}, {y}, {z})"

    @tool
    def open_gripper() -> str:
        """Open the robot gripper."""
        arm.gripper_open()
        return "Gripper opened"

    @tool
    def close_gripper() -> str:
        """Close the robot gripper."""
        arm.gripper_close()
        return "Gripper closed"

    @tool
    def get_position() -> str:
        """Get the current position of the robot arm."""
        pos = arm.get_pose()
        return f"Current position: ({pos.x}, {pos.y}, {pos.z})"

    @tool
    def look_at_workspace() -> str:
        """Take a photo and describe what's on the workspace."""
        frame = camera.capture()
        # Use vision model to describe scene
        description = describe_scene(frame)
        return description

    tools = [move_arm, open_gripper, close_gripper, get_position, look_at_workspace]

    llm = ChatOpenAI(model="gpt-4o")
    agent = create_tool_calling_agent(llm, tools, prompt)

    # Agent can now autonomously complete tasks
    agent.run("Pick up the blue block and place it on top of the red block")

Safety Considerations
---------------------

When using AI for robot control, always implement safety measures:

.. code-block:: python

    from mini_arm.safety import SafetyWrapper

    # Wrap arm with safety checks
    safe_arm = SafetyWrapper(
        arm,
        max_velocity=90,          # deg/s
        workspace_limits={        # mm
            "x": (-150, 150),
            "y": (-150, 150),
            "z": (0, 200),
        },
        collision_objects=[...],  # Known obstacles
        require_confirmation=True  # Ask before executing
    )

    # AI commands go through safety filter
    safe_arm.move_to(x=100, y=100, z=50)  # Validated before execution

Example: AI Teaching Assistant
------------------------------

Use Mini-Arm as an interactive teaching tool:

.. code-block:: python

    # Student asks about robot kinematics
    # LLM explains while demonstrating on the arm

    def teach(topic: str):
        if "forward kinematics" in topic.lower():
            response = """
            Forward kinematics calculates the end-effector position
            from joint angles. Watch as I demonstrate:
            """
            print(response)

            # Demonstrate by moving joints
            for i in range(6):
                print(f"Moving joint {i}...")
                arm.set_joint(i, 30)
                time.sleep(1)
                pos = arm.get_pose()
                print(f"End-effector now at: ({pos.x:.1f}, {pos.y:.1f}, {pos.z:.1f})")
                arm.set_joint(i, 0)

Next Steps
----------

- :doc:`/ros2/setup` - ROS2 integration for advanced AI
- `MicroLLM Project <https://github.com/Jshulgach/MicroLLM>`_ - On-device LLM for Pico

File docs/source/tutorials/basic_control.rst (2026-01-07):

Basic Control
=============

This tutorial covers the fundamentals of controlling your Mini-Arm.

Connecting to the Robot
-----------------------

.. code-block:: python

    from mini_arm import MiniArm

    # Create connection (auto-detects port)
    arm = MiniArm()
    arm.connect()

    # Verify connection
    if arm.is_connected:
        print("✓ Connected to Mini-Arm")
        print(f"  Firmware: {arm.firmware_version}")
        print(f"  Port: {arm.port}")

Joint Space Control
-------------------

Control individual joints by index (0-5) or name:

.. code-block:: python

    # Move by joint index
    arm.set_joint(0, 45)   # Base to 45°
    arm.set_joint(1, -30)  # Shoulder to -30°

    # Move by joint name
    arm.set_joint("base", 45)
    arm.set_joint("shoulder", -30)

    # Move all joints simultaneously
    joint_angles = [0, -45, 90, 0, 45, 0]
    arm.set_joints(joint_angles)

    # Get current joint positions
    current = arm.get_joints()
    print(f"Current angles: {current}")

Joint Speed Control
-------------------

.. code-block:: python

    # Set global speed (percentage of max)
    arm.set_speed(50)  # 50% speed

    # Set speed for specific joint
    arm.set_joint_speed(0, 25)  # Base at 25% speed

    # Move with custom duration
    arm.set_joint(0, 90, duration=2.0)  # Take 2 seconds

Cartesian Control (IK)
----------------------

Move the end-effector to XYZ positions using the onboard inverse kinematics solver:

.. code-block:: python

    # Move to position (mm)
    arm.move_to(x=100, y=0, z=150)

    # Move with orientation (degrees)
    arm.move_to(
        x=100, y=50, z=100,
        roll=0, pitch=90, yaw=0
    )

    # Relative movement
    arm.move_relative(dx=10, dy=0, dz=-20)

    # Get current pose
    pose = arm.get_pose()
    print(f"Position: ({pose.x}, {pose.y}, {pose.z})")
    print(f"Orientation: ({pose.roll}, {pose.pitch}, {pose.yaw})")

Gripper Operations
------------------

.. code-block:: python

    # Simple open/close
    arm.gripper_open()
    arm.gripper_close()

    # Partial opening (0-100%)
    arm.gripper_set(50)  # Half open

    # Check gripper state
    print(f"Gripper position: {arm.gripper_position}%")

Homing
------

.. code-block:: python

    # Move all joints to home (0°)
    arm.home()

    # Home individual joint
    arm.home_joint(0)

    # Set custom home position
    arm.set_home_position([0, -45, 90, 0, 45, 0])
    arm.home()  # Now goes to custom position

Complete Example
----------------

.. code-block:: python

    from mini_arm import MiniArm
    import time

    def main():
        # Connect
        arm = MiniArm()
        arm.connect()

        try:
            # Home the robot
            print("Homing...")
            arm.home()
            time.sleep(1)

            # Pick and place demo
            print("Moving to pick position...")
            arm.move_to(x=100, y=50, z=50)
            arm.gripper_open()
            
            print("Lowering...")
            arm.move_to(x=100, y=50, z=10)
            arm.gripper_close()
            
            print("Lifting...")
            arm.move_to(x=100, y=50, z=100)
            
            print("Moving to place position...")
            arm.move_to(x=-100, y=50, z=100)
            
            print("Placing...")
            arm.move_to(x=-100, y=50, z=10)
            arm.gripper_open()
            
            print("Done!")
            arm.home()

        finally:
            arm.disconnect()

    if __name__ == "__main__":
        main()

Next Steps
----------

- :doc:`trajectories` - Smooth multi-point motion
- :doc:`xbox_teleop` - Controller-based teleoperation

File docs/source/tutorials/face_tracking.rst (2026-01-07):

Face Tracking
=============

Use computer vision to track faces and have Mini-Arm follow them.

Requirements
------------

.. code-block:: bash

    pip install opencv-python mediapipe

Basic Face Tracking
-------------------

.. code-block:: python

    import cv2
    import mediapipe as mp
    from mini_arm import MiniArm

    # Initialize
    arm = MiniArm()
    arm.connect()

    mp_face = mp.solutions.face_detection
    face_detection = mp_face.FaceDetection(min_detection_confidence=0.7)

    cap = cv2.VideoCapture(0)

    # Camera center
    frame_center_x = 320
    frame_center_y = 240

    try:
        while cap.isOpened():
            ret, frame = cap.read()
            if not ret:
                break

            # Detect faces
            rgb = cv2.cvtColor(frame, cv2.COLOR_BGR2RGB)
            results = face_detection.process(rgb)

            if results.detections:
                # Get first face
                detection = results.detections[0]
                bbox = detection.location_data.relative_bounding_box

                # Calculate face center
                h, w, _ = frame.shape
                face_x = int((bbox.xmin + bbox.width / 2) * w)
                face_y = int((bbox.ymin + bbox.height / 2) * h)

                # Calculate error from center
                error_x = (face_x - frame_center_x) / frame_center_x
                error_y = (face_y - frame_center_y) / frame_center_y

                # Move arm to track face
                arm.jog_joint(0, -error_x * 5)  # Pan (base)
                arm.jog_joint(1, error_y * 3)   # Tilt (shoulder)

                # Draw tracking info
                cv2.circle(frame, (face_x, face_y), 5, (0, 255, 0), -1)
                cv2.rectangle(frame,
                    (int(bbox.xmin * w), int(bbox.ymin * h)),
                    (int((bbox.xmin + bbox.width) * w), int((bbox.ymin + bbox.height) * h)),
                    (0, 255, 0), 2)

            cv2.imshow("Face Tracking", frame)
            if cv2.waitKey(1) & 0xFF == ord('q'):
                break

    finally:
        cap.release()
        cv2.destroyAllWindows()
        arm.disconnect()

PID Control for Smooth Tracking
-------------------------------

.. code-block:: python

    class PIDController:
        def __init__(self, kp=1.0, ki=0.0, kd=0.1):
            self.kp = kp
            self.ki = ki
            self.kd = kd
            self.integral = 0
            self.prev_error = 0

        def update(self, error, dt=0.033):
            self.integral += error * dt
            derivative = (error - self.prev_error) / dt
            output = self.kp * error + self.ki * self.integral + self.kd * derivative
            self.prev_error = error
            return output

    # Use PID for smoother tracking
    pan_pid = PIDController(kp=2.0, ki=0.1, kd=0.5)
    tilt_pid = PIDController(kp=1.5, ki=0.1, kd=0.3)

    # In tracking loop:
    pan_correction = pan_pid.update(error_x)
    tilt_correction = tilt_pid.update(error_y)

    arm.jog_joint(0, pan_correction)
    arm.jog_joint(1, tilt_correction)

Multiple Face Handling
----------------------

.. code-block:: python

    if results.detections:
        # Track the largest (closest) face
        largest_face = max(results.detections,
            key=lambda d: d.location_data.relative_bounding_box.width *
                         d.location_data.relative_bounding_box.height)

        # Or track a specific face (face re-identification)
        # ... advanced implementation

Face Distance Estimation
------------------------

Use face size to estimate distance and adjust arm position:

.. code-block:: python

    # Approximate distance from face size
    face_width_pixels = bbox.width * w
    KNOWN_FACE_WIDTH_CM = 15  # Average face width
    FOCAL_LENGTH = 600        # Calibrated for your camera

    distance_cm = (KNOWN_FACE_WIDTH_CM * FOCAL_LENGTH) / face_width_pixels

    # Adjust arm reach based on distance
    target_z = 100 + (distance_cm - 50) * 0.5  # Example mapping
    arm.move_to(z=target_z)

Hand Gesture Integration
------------------------

Combine with hand tracking for gesture control:

.. code-block:: python

    import mediapipe as mp

    mp_hands = mp.solutions.hands
    hands = mp_hands.Hands(max_num_hands=1)

    # In loop:
    hand_results = hands.process(rgb)

    if hand_results.multi_hand_landmarks:
        hand = hand_results.multi_hand_landmarks[0]

        # Check for closed fist (gripper close)
        if is_fist(hand):
            arm.gripper_close()
        else:
            arm.gripper_open()

Complete Demo
-------------

Run the full face tracking demo:

.. code-block:: bash

    python examples/03_face_detection/face_track.py

Next Steps
----------

- :doc:`ai_integration` - Add LLM-based interaction
- :doc:`/ros2/setup` - ROS2 integration for advanced vision

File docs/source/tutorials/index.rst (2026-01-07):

Tutorials
=========

Learn how to use Mini-Arm through hands-on tutorials, from basic control to advanced AI integration.

.. grid:: 2

    .. grid-item-card:: 🎮 Basic Control
        :link: basic_control
        :link-type: doc

        Learn the fundamentals of joint and Cartesian control.

    .. grid-item-card:: 📈 Trajectories
        :link: trajectories
        :link-type: doc

        Plan and execute smooth multi-point trajectories.

    .. grid-item-card:: 🎯 Xbox Teleop
        :link: xbox_teleop
        :link-type: doc

        Control Mini-Arm with an Xbox controller.

    .. grid-item-card:: 👁️ Face Tracking
        :link: face_tracking
        :link-type: doc

        Track faces using computer vision and move the arm to follow.

    .. grid-item-card:: 🤖 AI Integration
        :link: ai_integration
        :link-type: doc

        Integrate with LLMs and computer vision for intelligent control.

Getting Started
---------------

If you haven't already, make sure to complete the :doc:`/getting_started/installation` guide first.

All tutorial code is available in the ``examples/`` directory of the repository.

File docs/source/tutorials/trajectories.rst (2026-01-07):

Trajectory Planning
===================

This tutorial covers planning and executing smooth multi-point trajectories.

Simple Waypoint Trajectory
--------------------------

.. code-block:: python

    from mini_arm import MiniArm

    arm = MiniArm()
    arm.connect()

    # Define waypoints (joint angles in degrees)
    waypoints = [
        [0, 0, 0, 0, 0, 0],        # Start (home)
        [45, -30, 60, 0, 30, 0],   # Point A
        [90, -45, 90, 0, 45, 0],   # Point B
        [-45, -30, 60, 0, 30, 0],  # Point C
        [0, 0, 0, 0, 0, 0],        # End (home)
    ]

    # Execute trajectory
    arm.execute_trajectory(waypoints, duration=10.0)

Cartesian Trajectories
----------------------

Define waypoints in Cartesian space:

.. code-block:: python

    # XYZ waypoints
    cartesian_waypoints = [
        {"x": 100, "y": 0, "z": 150},
        {"x": 100, "y": 50, "z": 100},
        {"x": 100, "y": -50, "z": 100},
        {"x": 100, "y": 0, "z": 150},
    ]

    arm.execute_cartesian_trajectory(cartesian_waypoints, duration=8.0)

Interpolation Methods
---------------------

.. code-block:: python

    from mini_arm import InterpolationType

    # Linear interpolation (default)
    arm.execute_trajectory(waypoints, interpolation=InterpolationType.LINEAR)

    # Cubic spline (smoother)
    arm.execute_trajectory(waypoints, interpolation=InterpolationType.CUBIC)

    # Quintic (smoothest, no jerk at waypoints)
    arm.execute_trajectory(waypoints, interpolation=InterpolationType.QUINTIC)

Velocity Profiles
-----------------

.. code-block:: python

    from mini_arm import VelocityProfile

    # Trapezoidal velocity (accelerate, cruise, decelerate)
    arm.execute_trajectory(
        waypoints,
        velocity_profile=VelocityProfile.TRAPEZOIDAL,
        max_velocity=90,        # deg/s
        max_acceleration=180,   # deg/s²
    )

    # S-curve (smooth acceleration)
    arm.execute_trajectory(
        waypoints,
        velocity_profile=VelocityProfile.SCURVE,
    )

Timed Waypoints
---------------

Specify exact timing for each waypoint:

.. code-block:: python

    timed_waypoints = [
        {"time": 0.0, "joints": [0, 0, 0, 0, 0, 0]},
        {"time": 2.0, "joints": [45, -30, 60, 0, 30, 0]},
        {"time": 3.5, "joints": [90, -45, 90, 0, 45, 0]},  # Faster segment
        {"time": 6.0, "joints": [-45, -30, 60, 0, 30, 0]},
        {"time": 8.0, "joints": [0, 0, 0, 0, 0, 0]},
    ]

    arm.execute_timed_trajectory(timed_waypoints)

Real-time Streaming
-------------------

For applications requiring real-time control:

.. code-block:: python

    import time
    import math

    # Stream positions at high rate
    arm.start_streaming(rate=50)  # 50 Hz

    t = 0
    while t < 10:
        # Generate sinusoidal motion
        angle = 45 * math.sin(2 * math.pi * 0.5 * t)
        arm.stream_joint(0, angle)
        
        time.sleep(0.02)  # 50 Hz
        t += 0.02

    arm.stop_streaming()

Recording and Playback
----------------------

Record a trajectory by moving the arm manually:

.. code-block:: python

    # Enable gravity compensation / freedrive mode
    arm.enable_freedrive()

    print("Move the arm... Press Enter when done.")
    arm.start_recording(rate=20)  # Record at 20 Hz
    input()
    trajectory = arm.stop_recording()

    arm.disable_freedrive()

    # Save trajectory
    trajectory.save("my_trajectory.json")

    # Load and replay
    loaded = Trajectory.load("my_trajectory.json")
    arm.execute_trajectory(loaded)

Visualization
-------------

Visualize trajectories before execution:

.. code-block:: python

    from mini_arm.viz import plot_trajectory

    # Plot joint space trajectory
    plot_trajectory(waypoints, show=True)

    # Plot Cartesian path
    plot_trajectory(waypoints, space="cartesian", show=True)

    # Animate in 3D viewer
    arm.visualize_trajectory(waypoints, animate=True)

Complete Example: Drawing a Square
----------------------------------

.. code-block:: python

    from mini_arm import MiniArm

    arm = MiniArm()
    arm.connect()

    # Define square in XY plane at Z=50mm
    z_height = 50
    size = 80  # mm

    square_path = [
        {"x": size/2, "y": size/2, "z": z_height},
        {"x": -size/2, "y": size/2, "z": z_height},
        {"x": -size/2, "y": -size/2, "z": z_height},
        {"x": size/2, "y": -size/2, "z": z_height},
        {"x": size/2, "y": size/2, "z": z_height},  # Close the square
    ]

    # Move to start position (raised)
    arm.move_to(x=size/2, y=size/2, z=z_height + 50)

    # Lower to drawing height
    arm.move_to(x=size/2, y=size/2, z=z_height)

    # Draw the square
    arm.execute_cartesian_trajectory(square_path, duration=8.0)

    # Raise and home
    arm.move_relative(dz=50)
    arm.home()

Next Steps
----------

- :doc:`xbox_teleop` - Real-time control with a gamepad
- :doc:`ai_integration` - LLM-powered trajectory generation

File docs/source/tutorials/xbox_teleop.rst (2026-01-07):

Xbox Controller Teleoperation
=============================

Control your Mini-Arm in real-time using an Xbox controller.

Requirements
------------

.. code-block:: bash

    pip install pygame

Controller Setup
----------------

1. Connect your Xbox controller via USB or Bluetooth
2. Verify it's detected by your OS

Run the demo:

.. code-block:: bash

    python examples/02_xbox_teleop/teleop.py

Control Mapping
---------------

.. list-table::
   :header-rows: 1
   :widths: 30 70

   * - Button/Axis
     - Action
   * - Left Stick X
     - Base rotation (J0)
   * - Left Stick Y
     - Shoulder (J1)
   * - Right Stick X
     - Wrist yaw (J5)
   * - Right Stick Y
     - Elbow (J2)
   * - LT / RT
     - Gripper close / open
   * - LB
     - Decrease speed
   * - RB
     - Increase speed
   * - A
     - Home position
   * - B
     - Emergency stop
   * - X
     - Toggle Cartesian mode
   * - Y
     - Save waypoint
   * - Start
     - Execute saved trajectory

Basic Teleop Script
-------------------

.. code-block:: python

    from mini_arm import MiniArm
    from mini_arm.teleop import XboxController

    arm = MiniArm()
    arm.connect()

    controller = XboxController()

    print("Xbox Teleop Active")
    print("Press B to stop, A to home")

    speed = 50
    arm.set_speed(speed)

    try:
        while True:
            # Read controller state
            state = controller.get_state()

            if state.b_pressed:
                print("Stopping...")
                break

            if state.a_pressed:
                arm.home()
                continue

            # Speed adjustment
            if state.lb_pressed:
                speed = max(10, speed - 10)
                arm.set_speed(speed)
                print(f"Speed: {speed}%")

            if state.rb_pressed:
                speed = min(100, speed + 10)
                arm.set_speed(speed)
                print(f"Speed: {speed}%")

            # Joint control from sticks
            arm.jog_joint(0, state.left_stick_x * 2)   # Base
            arm.jog_joint(1, state.left_stick_y * 2)   # Shoulder
            arm.jog_joint(2, state.right_stick_y * 2)  # Elbow
            arm.jog_joint(5, state.right_stick_x * 2)  # Wrist

            # Gripper
            if state.right_trigger > 0.1:
                arm.gripper_set(100 - state.right_trigger * 100)
            elif state.left_trigger > 0.1:
                arm.gripper_set(state.left_trigger * 100)

    finally:
        arm.disconnect()
        controller.close()

Cartesian Mode
--------------

Toggle to Cartesian control with the X button:

.. code-block:: python

    cartesian_mode = False

    if state.x_pressed:
        cartesian_mode = not cartesian_mode
        print(f"Cartesian mode: {cartesian_mode}")

    if cartesian_mode:
        # Sticks control XYZ position
        arm.jog_cartesian(
            dx=state.left_stick_x * 5,
            dy=state.left_stick_y * 5,
            dz=(state.right_trigger - state.left_trigger) * 5
        )
    else:
        # Normal joint control
        # ...

Recording Trajectories
----------------------

Use the controller to record and playback trajectories:

.. code-block:: python

    waypoints = []
    recording = False

    if state.y_pressed:
        # Save current position as waypoint
        current = arm.get_joints()
        waypoints.append(current)
        print(f"Saved waypoint {len(waypoints)}")

    if state.start_pressed and waypoints:
        print(f"Executing {len(waypoints)} waypoints...")
        arm.execute_trajectory(waypoints, duration=len(waypoints) * 2)
        waypoints = []

Deadzone Configuration
----------------------

.. code-block:: python

    controller = XboxController(
        deadzone=0.15,           # Ignore small stick movements
        trigger_threshold=0.1,   # Trigger activation threshold
    )

Vibration Feedback
------------------

.. code-block:: python

    # Vibrate on collision warning
    if arm.near_limit():
        controller.vibrate(intensity=0.5, duration=0.2)

    # Vibrate on waypoint save
    if state.y_pressed:
        controller.vibrate(intensity=1.0, duration=0.1)

Next Steps
----------

- :doc:`face_tracking` - Vision-based control
- :doc:`ai_integration` - Natural language commands

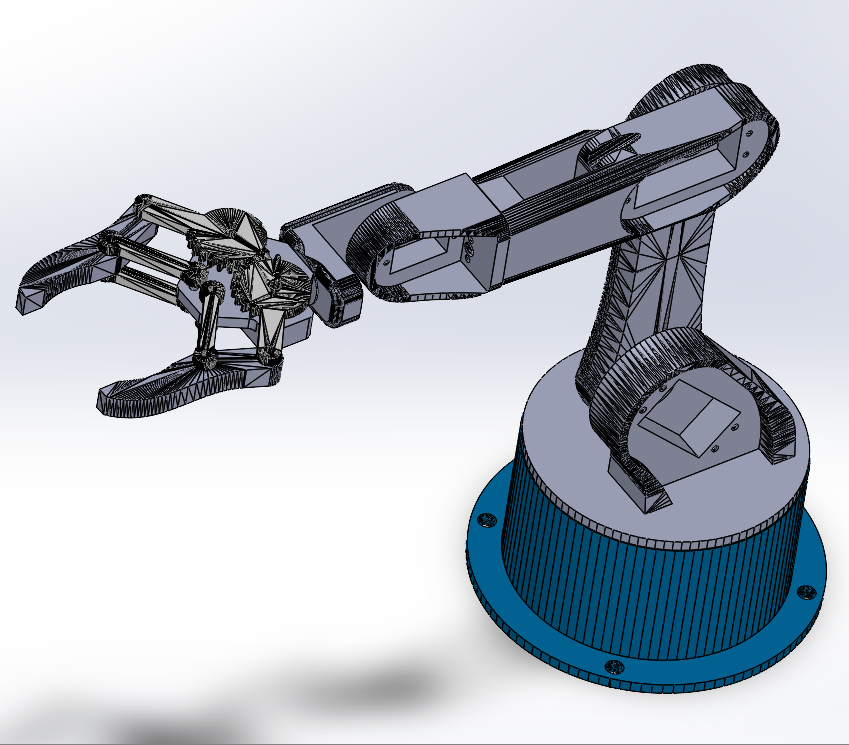
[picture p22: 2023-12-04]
assets/MiniArm Assembly.PNG

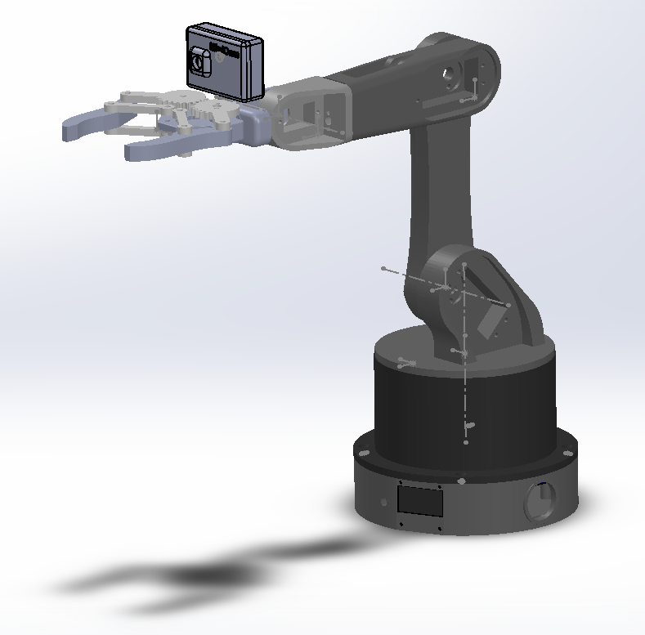
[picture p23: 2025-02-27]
assets/assembly2.PNG

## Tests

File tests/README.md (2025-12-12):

# Mini-Arm Tests

Test scripts for validating Mini-Arm functionality across hardware, kinematics, networking, and visualization.

## Test Categories

### Hardware Tests (`hardware/`)

Tests for serial communication and servo control:

- **serial_test_HOST.py** - Test serial communication from host PC
- **serial_test_PICO.py** - Test serial communication on Pico
- **UART_serial_write_PICO_test.py** - Test UART serial writes from Pico
- **PICOmultiservo_test.py** - Test controlling multiple servos simultaneously

### Kinematics Tests (`kinematics/`)

Inverse kinematics and transformation tests:

- **ikpy_test.py** - Test ikpy library for IK solving
- **PICOikpy_test.py** - Test ikpy on Pico microcontroller
- **ik_numerical_test.py** - Numerical IK solver tests
- **ik_symbolic_test.py** - Symbolic IK solver tests
- **mini_ik_numerical_test.py** - Numerical IK optimized for Mini-Arm
- **alberto_ik_test.py** - Test IK implementation from Alberto Abarzua
- **total_transform_test.py** - Test complete transformation chain

### Networking Tests (`networking/`)

Network communication and streaming:

- **esp32cam-stream-test.py** - Test ESP32-CAM video streaming integration

### Visualization Tests (`visualization/`)

3D visualization and robot simulation:

- **rtb_miniarm_test.py** - Test Mini-Arm with Robotics Toolbox (Peter Corke)
- **rtb_panda_test.py** - Test Panda robot model
- **rtb_swift_test.py** - Test Swift web-based 3D visualization
- **rtpy_test.py** - Test rtpy (Robotics Toolbox Python)
- **PICOtrajectory_test.py** - Test trajectory execution on Pico

## Running Tests

Most tests can be run directly:

```bash
# Run a hardware test
python tests/hardware/serial_test_HOST.py

# Run a kinematics test
python tests/kinematics/ik_numerical_test.py

# Run a visualization test
python tests/visualization/rtb_miniarm_test.py
```

### Dependencies

Tests may require additional packages:
- `ikpy` - Inverse kinematics
- `roboticstoolbox-python` - Robot modeling and visualization
- `swift` - 3D web visualization
- `opencv-python` - Computer vision (for camera tests)

Install all test dependencies:
```bash
pip install ikpy roboticstoolbox-python opencv-python
```

## Test Organization

Tests are organized by functionality:
- **Hardware** - Low-level communication and servo control
- **Kinematics** - IK solvers and coordinate transformations
- **Networking** - TCP/IP, WebSocket, camera streaming
- **Visualization** - 3D rendering, simulation, RViz

## Notes

- Pico tests require CircuitPython firmware and must be run on the microcontroller
- Visualization tests require OpenGL support
- Some tests generate demo GIFs or data files in their local directory

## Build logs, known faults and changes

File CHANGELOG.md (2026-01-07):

# Changelog

All notable changes to this project will be documented in this file.

The format is based on [Keep a Changelog](https://keepachangelog.com/en/1.1.0/),
and this project adheres to [Semantic Versioning](https://semver.org/spec/v2.0.0.html).

## [0.3.0] - 2025-01-07

### Added
- Proper Python package structure with `pip install` support
- `pyproject.toml` for modern Python packaging
- Command-line interface via `mini-arm` command
- Context manager support for `MiniArmClient`
- New convenience methods: `set_pose()`, `set_joints()`, `set_led()`, `set_gripper()`
- Comprehensive Sphinx documentation
- GitHub Actions workflows for docs deployment and CI testing
- Organized hardware directory with CAD, STL, and BOM files

### Changed
- Restructured repository for better organization
- Moved firmware to `firmware/circuitpython/`
- Moved ROS2 packages to `ros2/`
- Moved CAD/STL/BOM to `hardware/`
- Refactored `mini_arm.py` into proper package under `src/mini_arm/`
- Updated README with new structure and installation instructions

### Deprecated
- Old import from root `mini_arm.py` (use `from mini_arm import MiniArmClient` instead)
- Old `pico/` directory path (now `firmware/circuitpython/`)
- Old `miniarm_ros/` directory path (now `ros2/`)

## [0.2.0] - 2024-xx-xx

### Added
- Xbox controller teleop support
- Trajectory execution examples
- Motion analysis tools
- Multiple CircuitPython firmware versions

### Changed
- Improved serial communication reliability
- Enhanced IK solver performance

## [0.1.0] - 2024-xx-xx

### Added
- Initial release
- MiniArmClient for serial communication
- CircuitPython firmware for Raspberry Pi Pico
- Basic control examples
- ROS2 visualization packages

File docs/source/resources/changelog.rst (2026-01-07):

Changelog
=========

All notable changes to Mini-Arm.

[1.0.0] - 2025-XX-XX
--------------------

**Added**

- Complete documentation site with Sphinx
- Full API reference
- Hardware assembly guide with step-by-step instructions
- ROS2 Humble support with MoveIt2 integration
- Xbox controller teleoperation
- Face tracking example
- AI/LLM integration tutorials
- Bill of Materials with links
- 3D printing guide

**Changed**

- Migrated to Raspberry Pi Pico 2
- Updated CircuitPython to latest version
- Improved IK solver performance
- Enhanced trajectory interpolation

**Fixed**

- Gripper calibration issues
- Serial timeout handling
- Joint limit enforcement

[0.2.0] - 2024-XX-XX
--------------------

**Added**

- Cartesian control with onboard IK
- Trajectory execution with interpolation
- ROS2 package (beta)
- Basic visualization

**Changed**

- Refactored serial protocol
- Improved calibration routine

[0.1.0] - 2023-XX-XX
--------------------

**Initial Release**

- Basic joint control
- CircuitPython firmware for Pico
- Python client library
- 3D printable design files
- Simple examples

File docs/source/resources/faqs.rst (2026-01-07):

Frequently Asked Questions
==========================

General
-------

**What is Mini-Arm?**

Mini-Arm is a miniature 6-DOF 3D-printed robot arm designed for education, research, and hobbyist projects. It runs on a Raspberry Pi Pico with CircuitPython firmware and includes a built-in inverse kinematics solver.

**How much does it cost to build?**

The complete build costs approximately $80-100 USD, with the main expenses being servos ($20-30) and the Raspberry Pi Pico ($5).

**What's the payload capacity?**

With the stock MG90S servos, Mini-Arm can lift approximately 50-100 grams at full extension. Upgrading to MG996R servos increases this to ~200g.

**What's the reach/workspace?**

- Maximum reach: ~200mm from base center
- Vertical reach: ~250mm
- Full 360° base rotation

Hardware
--------

**What servos should I use?**

- **Stock (recommended)**: MG90S micro servos - good balance of torque/size
- **Budget**: SG90 - works but less torque
- **Upgraded**: MG996R - more torque, requires larger printed parts

**Can I use a different microcontroller?**

The firmware is designed for Raspberry Pi Pico but can be adapted:

- Pico W - adds WiFi capability
- ESP32 - requires firmware port
- Arduino - possible but limited flash/RAM

**Why isn't my servo moving smoothly?**

1. Check power supply - servos need 5V 3A
2. Reduce speed: ``arm.set_speed(30)``
3. Check for mechanical binding
4. Add capacitor (100-1000µF) on power line

Software
--------

**What Python version is required?**

Python 3.8 or higher.

**Can I use Mini-Arm without ROS2?**

Yes! The Python client library works standalone. ROS2 is optional for advanced features.

**How do I update the firmware?**

1. Connect Pico while holding BOOTSEL
2. Drag new CircuitPython UF2 to RPI-RP2
3. Copy updated ``pico/`` folder contents to CIRCUITPY

**The IK solver fails - what should I do?**

The position may be outside the workspace:

.. code-block:: python

    from mini_arm.kinematics import is_reachable

    if is_reachable(x, y, z):
        arm.move_to(x, y, z)
    else:
        print("Position out of reach!")

Alternatively, the configuration may be singular (e.g., arm fully extended).

Troubleshooting
---------------

**"Port not found" error**

1. Check USB connection
2. Verify Pico is running CircuitPython (CIRCUITPY drive visible)
3. Try specifying port manually:

.. code-block:: python

    arm = MiniArm(port="COM3")  # Windows
    arm = MiniArm(port="/dev/ttyACM0")  # Linux

**Servos jitter or make noise**

- Normal holding torque hum is expected
- Excessive jitter: check wiring, add capacitor
- Use ``arm.disable_freedrive()`` when not moving to reduce stress

**Arm moves to wrong position**

Calibration may be off:

.. code-block:: bash

    python -m mini_arm.calibrate

**"I2C device not found" error**

- Check GP0 → SDA, GP1 → SCL connections
- Verify 3.3V power to PCA9685
- Test with I2C scanner

3D Printing
-----------

**What material should I use?**

PLA is fine for most uses. Use PETG for more durability.

**My parts don't fit together**

- Print a calibration cube first
- Adjust horizontal expansion in slicer (-0.1 to -0.2mm)
- Light sanding on tight fits

**How long does printing take?**

Approximately 12-15 hours total for all parts at 0.2mm layer height.

Community
---------

**Where can I get help?**

- GitHub Issues: `github.com/Jshulgach/Mini-Arm/issues <https://github.com/Jshulgach/Mini-Arm/issues>`_
- Discussions: `github.com/Jshulgach/Mini-Arm/discussions <https://github.com/Jshulgach/Mini-Arm/discussions>`_

**Can I contribute?**

Yes! See :doc:`contributing` for guidelines.

**Can I use Mini-Arm commercially?**

Mini-Arm is MIT licensed - you can use it for any purpose, including commercial, as long as you include the license.

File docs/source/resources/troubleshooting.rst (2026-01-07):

Troubleshooting
===============

Common issues and solutions for Mini-Arm.

Connection Issues
-----------------

**"Port not found" or "Could not open port"**

.. code-block:: text

    ✗ Check: Is the Pico connected via USB?
    ✗ Check: Does CIRCUITPY drive appear?
    ✗ Check: Is another program using the port?

Solutions:

1. Unplug and replug USB cable
2. Close any serial monitors (Arduino IDE, PuTTY, etc.)
3. Check Device Manager (Windows) or ``ls /dev/tty*`` (Linux)
4. Specify port explicitly:

.. code-block:: python

    arm = MiniArm(port="COM3")  # Windows
    arm = MiniArm(port="/dev/ttyACM0")  # Linux/Mac

**"I2C device not found"**

The Pico can't communicate with the PCA9685 servo driver.

.. code-block:: text

    ✗ Check: Is VCC connected to 3.3V?
    ✗ Check: Is SDA connected to GP0?
    ✗ Check: Is SCL connected to GP1?
    ✗ Check: Is GND connected?

Test I2C:

.. code-block:: python

    # On the Pico (via serial REPL)
    import board
    import busio
    i2c = busio.I2C(board.GP1, board.GP0)
    while not i2c.try_lock():
        pass
    print(i2c.scan())  # Should show [64] for PCA9685
    i2c.unlock()

Servo Issues
------------

**Servo doesn't move**

1. Check V+ power connection (5V to PCA9685 V+ terminal)
2. Verify servo is connected to correct channel
3. Test servo directly:

.. code-block:: python

    arm.set_servo_raw(0, 1500)  # Should move to center

4. Try a known-good servo to rule out hardware failure

**Servo jitters or buzzes**

- **Normal**: Slight holding hum is expected
- **Excessive jitter**:
  - Insufficient power - use 5V 3A supply
  - Add 100-1000µF capacitor on V+ line
  - Check for loose connections

**Servo overheats**

- Don't leave arm under continuous load
- Check for mechanical binding
- Reduce holding torque when idle:

.. code-block:: python

    arm.set_speed(30)  # Lower speed = less stress
    arm.enable_freedrive()  # Disable holding when not moving

**Servo moves to wrong angle**

Run calibration:

.. code-block:: bash

    python -m mini_arm.calibrate

Or manually adjust offsets:

.. code-block:: python

    arm.set_joint_offset(0, 5.0)  # Add 5° offset to joint 0

Motion Issues
-------------

**IK solver fails ("Position unreachable")**

The target is outside the workspace:

.. code-block:: python

    from mini_arm.kinematics import is_reachable, workspace_boundary

    # Check if reachable
    if not is_reachable(x, y, z):
        print("Target outside workspace")
        print(workspace_boundary())

**Arm moves in wrong direction**

Servo may be installed backwards. Options:

1. Physically reinstall servo rotated 180°
2. Invert joint in software:

.. code-block:: python

    arm.set_joint_direction(0, -1)  # Invert joint 0

**Jerky or stuttering motion**

1. Reduce speed:

.. code-block:: python

    arm.set_speed(30)

2. Use trajectory interpolation:

.. code-block:: python

    arm.execute_trajectory(waypoints, interpolation="cubic")

3. Check for mechanical issues (binding, friction)

Firmware Issues
---------------

**CIRCUITPY drive not appearing**

1. Hold BOOTSEL and plug in USB
2. Drag CircuitPython UF2 to RPI-RP2 drive
3. Wait for CIRCUITPY to appear

**"ImportError: No module named 'mini_arm'"**

Copy the lib folder correctly:

.. code-block:: text

    CIRCUITPY/
    └── lib/
        ├── adafruit_pca9685.mpy
        ├── adafruit_motor/
        └── mini_arm/
            ├── __init__.py
            └── ...

**Pico crashes or resets**

- Check for short circuits
- Verify power supply is adequate
- Check code.py for errors (connect serial terminal)

ROS2 Issues
-----------

**"Package not found"**

.. code-block:: bash

    source ~/miniarm_ws/install/setup.bash

Add to ``~/.bashrc`` for permanent fix.

**MoveIt planning fails**

- Check for collisions in planning scene
- Increase planning timeout
- Try different planner (RRTConnect, PRM, etc.)

**TF errors**

Ensure robot state publisher is running:

.. code-block:: bash

    ros2 topic echo /joint_states

Getting More Help
-----------------

If you're still stuck:

1. Check GitHub Issues: `Mini-Arm Issues <https://github.com/Jshulgach/Mini-Arm/issues>`_
2. Enable debug logging:

.. code-block:: python

    import logging
    logging.basicConfig(level=logging.DEBUG)
    arm = MiniArm(debug=True)

3. Open a new issue with:
   - Error message (full traceback)
   - OS and Python version
   - Steps to reproduce

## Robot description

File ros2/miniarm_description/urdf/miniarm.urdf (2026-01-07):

<?xml version="1.0" ?>
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
<robot name="miniarm" xmlns:xacro="http://www.ros.org/wiki/xacro">

  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
  <link name="miniarm_electronics">
    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
  </link>

  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
  <link name="miniarm_base">
    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
  </link>

  <joint name="miniarm_joint0" type="fixed">
    <origin xyz="0.015 0.025 0.082" rpy="0 0 0" />
    <parent link="miniarm_electronics" />
    <child link="miniarm_base" />
  </joint>

  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
  <link name="miniarm_link1">
    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
  </link>

  <joint name="miniarm_joint1" type="revolute">
    <origin xyz="-0.015 -0.024 0.004" rpy="1.5707963267948966 0 1.5707963267948966" />
    <parent link="miniarm_base" />
    <child link="miniarm_link1" />
    <axis xyz="0 1 0" />
    <limit effort="10" lower="-1.5708" upper="1.5708" velocity="2" />
  </joint>

  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
  <link name="miniarm_link2">
    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
  </link>

  <joint name="miniarm_joint2" type="revolute">
    <origin xyz="0.0 0.0415 -0.015" rpy="0 1.5708 0" />
    <parent link="miniarm_link1" />
    <child link="miniarm_link2" />
    <axis xyz="0 0 1" />
    <limit effort="10" lower="-1.5708" upper="1.5708" velocity="2" />
  </joint>

  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
  <link name="miniarm_link3">
    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
  </link>

  <joint name="miniarm_joint3" type="revolute">
    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
    <origin xyz="0.0 0.12 0" rpy="0 3.1416 1.5708" />
    <parent link="miniarm_link2" />
    <child link="miniarm_link3" />
    <axis xyz="0 0 1" />
    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
    <limit effort="10" lower="-0.785" upper="2.3561" velocity="2" />
  </joint>

  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
  <link name="miniarm_link4">
    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
  </link>

  <joint name="miniarm_joint4" type="revolute">
    <origin xyz="-0.0055 0.09 0.0135" rpy="0 0 0" />
    <parent link="miniarm_link3" />
    <child link="miniarm_link4" />
    <axis xyz="0 1 0" />
    <limit effort="10" lower="-1.5708" upper="1.5708" velocity="2" />
  </joint>

  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
  <link name="miniarm_link5">
    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
  </link>

  <joint name="miniarm_joint5" type="revolute">
    <origin xyz="0.005 0.028 -0.01" rpy="0 3.141592653589793 -1.5708" />
    <parent link="miniarm_link4" />
    <child link="miniarm_link5" />
    <axis xyz="0 0 1" />
    <limit effort="10" lower="-1.5708" upper="1.5708" velocity="2" />
  </joint>

  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
  <link name="miniarm_gripper_link">
    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
  </link>

  <joint name="miniarm_gripper_link_joint" type="revolute">
    <origin xyz="0.042 0.004 -0.006" rpy="0 1.5708 0" />
    <parent link="miniarm_link5" />
    <child link="miniarm_gripper_link" />
    <axis xyz="0 0 1" />
    <limit effort="10" lower="-1.5708" upper="1.5708" velocity="2" />
  </joint>

  <link name="miniarm_left_knuckle_link">
    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
  </link>

  <link name="miniarm_right_knuckle_link">
    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
  </link>

  <link name="miniarm_left_bottom_knuckle_link">
    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
  </link>

  <link name="miniarm_right_bottom_knuckle_link">
    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
  </link>

  <link name="miniarm_left_inner_knuckle_link">
    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
  </link>

  <link name="miniarm_right_inner_knuckle_link">
    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
  </link>

  <link name="miniarm_left_inner_bottom_knuckle_link">
    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
  </link>

  <link name="miniarm_right_inner_bottom_knuckle_link">
    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
  </link>

  <link name="miniarm_left_finger_link">
    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
  </link>

  <link name="miniarm_right_finger_link">
    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
  </link>

  <joint name="miniarm_gripper_joint" type="revolute">
    <origin xyz="-0.013 0.01 0.02" rpy="0 -1.5708 0" />
    <parent link="miniarm_gripper_link" />
    <child link="miniarm_left_knuckle_link" />
    <axis xyz="0 1 0" />
    <limit effort="10" lower="-2.35619" upper="0" velocity="2" />
  </joint>

  <joint name="miniarm_right_knuckle_joint" type="continuous">
    <origin xyz="0.013 0.01 0.02" rpy="0 -1.5708 0" />
    <parent link="miniarm_gripper_link" />
    <child link="miniarm_right_knuckle_link" />
    <axis xyz="0 1 0" />
    <mimic joint="miniarm_gripper_joint" multiplier="-1" offset="0"/>
  </joint>

  <joint name="miniarm_left_bottom_knuckle_joint" type="continuous">
    <origin xyz="-0.013 -0.004 0.02" rpy="0 -1.5708 0" />
    <parent link="miniarm_gripper_link" />
    <child link="miniarm_left_bottom_knuckle_link" />
    <axis xyz="0 1 0" />
    <mimic joint="miniarm_gripper_joint" multiplier="1" offset="0"/>
  </joint>

  <joint name="miniarm_right_bottom_knuckle_joint" type="continuous">
    <origin xyz="0.013 -0.004 0.02" rpy="0 -1.5708 0" />
    <parent link="miniarm_gripper_link" />
    <child link="miniarm_right_bottom_knuckle_link" />
    <axis xyz="0 1 0" />
    <mimic joint="miniarm_gripper_joint" multiplier="-1" offset="0"/>
  </joint>

  <joint name="miniarm_left_inner_knuckle_joint" type="continuous">
    <origin xyz="-0.005 0.01 0.041" rpy="0 -1.5708 0" />
    <parent link="miniarm_gripper_link" />
    <child link="miniarm_left_inner_knuckle_link" />
    <axis xyz="0 1 0" />
    <mimic joint="miniarm_gripper_joint" multiplier="1" offset="0"/>
  </joint>

  <joint name="miniarm_right_inner_knuckle_joint" type="continuous">
    <origin xyz="0.005 0.01 0.041" rpy="0 -1.5708 0" />
    <parent link="miniarm_gripper_link" />
    <child link="miniarm_right_inner_knuckle_link" />
    <axis xyz="0 1 0" />
    <mimic joint="miniarm_gripper_joint" multiplier="-1" offset="0"/>
  </joint>

  <joint name="miniarm_left_inner_bottom_knuckle_joint" type="continuous">
    <origin xyz="-0.005 -0.004 0.041" rpy="0 -1.5708 0" />
    <parent link="miniarm_gripper_link" />
    <child link="miniarm_left_inner_bottom_knuckle_link" />
    <axis xyz="0 1 0" />
    <mimic joint="miniarm_gripper_joint" multiplier="1" offset="0"/>
  </joint>

  <joint name="miniarm_right_inner_bottom_knuckle_joint" type="continuous">
    <origin xyz="0.005 -0.004 0.041" rpy="0 -1.5708 0" />
    <parent link="miniarm_gripper_link" />
    <child link="miniarm_right_inner_bottom_knuckle_link" />
    <axis xyz="0 1 0" />
    <mimic joint="miniarm_gripper_joint" multiplier="-1" offset="0"/>
  </joint>

  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
  <joint name="miniarm_left_finger_joint" type="continuous">
    <origin xyz="0.031 -0.001 0.0" rpy="1.22173 0 -1.5708" />
    <parent link="miniarm_left_knuckle_link" />
    <child link="miniarm_left_finger_link" />
    <axis xyz="1 0 0" />
    <limit effort="10" lower="-2.35619" upper="0" velocity="2" />
    <mimic joint="miniarm_gripper_joint" multiplier="1" offset="0"/>
  </joint>

  <joint name="miniarm_right_finger_joint" type="continuous">
    <origin xyz="0.031 -0.009 0.0" rpy="-1.9199 0 1.5708" />
    <parent link="miniarm_right_knuckle_link" />
    <child link="miniarm_right_finger_link" />
    <axis xyz="1 0 0" />
    <limit effort="10" lower="-2.35619" upper="0" velocity="2" />
    <mimic joint="miniarm_gripper_joint" multiplier="1" offset="0"/>
  </joint>

</robot>

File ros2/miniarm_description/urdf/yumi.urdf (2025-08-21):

<?xml version="1.0" ?>
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
<robot name="yumi" xmlns:xacro="http://www.ros.org/wiki/xacro">
  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
  <link name="yumi_base_link"/>
  <joint name="yumi_base_link_to_body" type="fixed">
    <parent link="yumi_base_link"/>
    <child link="yumi_body"/>
    <origin rpy="0 0 0" xyz="0 0 0"/>
  </joint>
  <link name="yumi_body">
    <inertial>
      <origin rpy="0 0 0" xyz="0 0 0"/>
      <mass value="15"/>
      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
    </inertial>
    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
  </link>
  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
  <joint name="yumi_joint_1_r" type="revolute">
    <parent link="yumi_body"/>
    <child link="yumi_link_1_r"/>
    <origin rpy="-0.9795 -0.5682 -2.3155" xyz="0.05355 -0.0725 0.41492"/>
    <axis xyz="0 0 1"/>
    <limit effort="300" lower="-2.94087978961" upper="2.94087978961" velocity="3.14159265359"/>
    <dynamics damping="0.5"/>
  </joint>
  <link name="yumi_link_1_r">
    <inertial>
      <origin rpy="0 0 0" xyz="0 -0.03 0.12"/>
      <mass value="2"/>
      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
    </inertial>
    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
  </link>
  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
  <joint name="yumi_joint_2_r" type="revolute">
    <parent link="yumi_link_1_r"/>
    <child link="yumi_link_2_r"/>
    <origin rpy="1.57079632679 0.0 0.0" xyz="0.03 0.0 0.1"/>
    <axis xyz="0 0 1"/>
    <limit effort="300" lower="-2.50454747661" upper="0.759218224618" velocity="3.14159265359"/>
    <dynamics damping="0.5"/>
  </joint>
  <link name="yumi_link_2_r">
    <inertial>
      <origin rpy="0 0 0" xyz="0 0 0"/>
      <mass value="2"/>
      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
    </inertial>
    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
  </link>
  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
  <joint name="yumi_joint_7_r" type="revolute">
    <parent link="yumi_link_2_r"/>
    <child link="yumi_link_3_r"/>
    <origin rpy="-1.57079632679 0.0 0.0" xyz="-0.03 0.17283 0.0"/>
    <axis xyz="0 0 1"/>
    <limit effort="300" lower="-2.94087978961" upper="2.94087978961" velocity="3.14159265359"/>
    <dynamics damping="0.5"/>
  </joint>
  <link name="yumi_link_3_r">
    <inertial>
      <origin rpy="0 0 0" xyz="0 0 0"/>
      <mass value="2"/>
      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
    </inertial>
    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
  </link>
  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
  <joint name="yumi_joint_3_r" type="revolute">
    <parent link="yumi_link_3_r"/>
    <child link="yumi_link_4_r"/>
    <origin rpy="1.57079632679 -1.57079632679 0.0" xyz="-0.04188 0.0 0.07873"/>
    <axis xyz="0 0 1"/>
    <limit effort="300" lower="-2.15548162621" upper="1.3962634016" velocity="3.14159265359"/>
    <dynamics damping="0.5"/>
  </joint>
  <link name="yumi_link_4_r">
    <inertial>
      <origin rpy="0 0 0" xyz="0 0 0"/>
      <mass value="2"/>
      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
    </inertial>
    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
  </link>
  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
  <joint name="yumi_joint_4_r" type="revolute">
    <parent link="yumi_link_4_r"/>
    <child link="yumi_link_5_r"/>
    <origin rpy="-1.57079632679 0.0 0.0" xyz="0.0405 0.16461 0.0"/>
    <axis xyz="0 0 1"/>
    <limit effort="300" lower="-5.06145483078" upper="5.06145483078" velocity="6.98131700798"/>
    <dynamics damping="0.5"/>
  </joint>
  <link name="yumi_link_5_r">
    <inertial>
      <origin rpy="0 0 0" xyz="0 0 0"/>
      <mass value="2"/>
      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
    </inertial>
    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
  </link>
  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
  <joint name="yumi_joint_5_r" type="revolute">
    <parent link="yumi_link_5_r"/>
    <child link="yumi_link_6_r"/>
    <origin rpy="1.57079632679 0.0 0.0" xyz="-0.027 0 0.10039"/>
    <axis xyz="0 0 1"/>
    <limit effort="300" lower="-1.53588974176" upper="2.40855436775" velocity="6.98131700798"/>
    <dynamics damping="0.5"/>
  </joint>
  <link name="yumi_link_6_r">
    <inertial>
      <origin rpy="0 0 0" xyz="0 0 0"/>
      <mass value="2"/>
      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
    </inertial>
    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
  </link>
  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
  <joint name="yumi_joint_6_r" type="revolute">
    <parent link="yumi_link_6_r"/>
    <child link="yumi_link_7_r"/>
    <origin rpy="-1.57079632679 0.0 0.0" xyz="0.027 0.029 0.0"/>
    <axis xyz="0 0 1"/>
    <limit effort="300" lower="-3.99680398707" upper="3.99680398707" velocity="6.98131700798"/>
    <dynamics damping="0.5"/>
  </joint>
  <link name="yumi_link_7_r">
    <inertial>
      <origin rpy="0 0 0" xyz="0 0 0"/>
      <mass value="2"/>
      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
    </inertial>
    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
  </link>
  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
  <joint name="yumi_joint_1_l" type="revolute">
    <parent link="yumi_body"/>
    <child link="yumi_link_1_l"/>
    <origin rpy="0.9781 -0.5716 2.3180" xyz="0.05355 0.07250 0.41492"/>
    <axis xyz="0 0 1"/>
    <limit effort="300" lower="-2.94087978961" upper="2.94087978961" velocity="3.14159265359"/>
    <dynamics damping="0.5"/>
  </joint>
  <link name="yumi_link_1_l">
    <inertial>
      <origin rpy="0 0 0" xyz="0 -0.03 0.12"/>
      <mass value="2"/>
      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
    </inertial>
    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
  </link>
  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
  <joint name="yumi_joint_2_l" type="revolute">
    <parent link="yumi_link_1_l"/>
    <child link="yumi_link_2_l"/>
    <origin rpy="1.57079632679 0.0 0.0" xyz="0.03 0.0 0.1"/>
    <axis xyz="0 0 1"/>
    <limit effort="300" lower="-2.50454747661" upper="0.759218224618" velocity="3.14159265359"/>
    <dynamics damping="0.5"/>
  </joint>
  <link name="yumi_link_2_l">
    <inertial>
      <origin rpy="0 0 0" xyz="0 0 0"/>
      <mass value="2"/>
      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
    </inertial>
    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
  </link>
  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
  <joint name="yumi_joint_7_l" type="revolute">
    <parent link="yumi_link_2_l"/>
    <child link="yumi_link_3_l"/>
    <origin rpy="-1.57079632679 0.0 0.0" xyz="-0.03 0.17283 0.0"/>
    <axis xyz="0 0 1"/>
    <limit effort="300" lower="-2.94087978961" upper="2.94087978961" velocity="3.14159265359"/>
    <dynamics damping="0.5"/>
  </joint>
  <link name="yumi_link_3_l">
    <inertial>
      <origin rpy="0 0 0" xyz="0 0 0"/>
      <mass value="2"/>
      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
    </inertial>
    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
  </link>
  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

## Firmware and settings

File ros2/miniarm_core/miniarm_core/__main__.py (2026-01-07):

"""
Command-line interface for Mini-Arm control.

Usage:
    python -m mini_arm --port COM3
    python -m mini_arm --port COM3 --command "get_pose"
    python -m mini_arm --port COM3 --interactive
"""

import argparse
import sys
import time

from .client import MiniArmClient


def main():
    """Command-line interface for Mini-Arm control."""
    parser = argparse.ArgumentParser(
        description="Mini-Arm Robot Control Interface",
        formatter_class=argparse.RawDescriptionHelpFormatter,
        epilog="""
Examples:
  # Connect and get help
  python -m mini_arm --port COM3

  # Send a command
  python -m mini_arm --port COM3 --command "get_pose"

  # Move to position
  python -m mini_arm --port COM3 --command "set_pose:[0.135,0.0,0.22]"

  # Interactive mode
  python -m mini_arm --port COM3 --interactive

For more examples, see the examples/ directory.
        """,
    )

    parser.add_argument(
        "--port",
        type=str,
        default="COM3",
        help="Serial port (default: COM3, Linux: /dev/ttyACM0)",
    )
    parser.add_argument(
        "--baudrate",
        type=int,
        default=9600,
        help="Baudrate for serial connection (default: 9600)",
    )
    parser.add_argument(
        "--command",
        type=str,
        default="help",
        help="Command to send to Mini-Arm (default: help)",
    )
    parser.add_argument(
        "--interactive",
        action="store_true",
        help="Enter interactive mode for sending multiple commands",
    )
    parser.add_argument("--verbose", action="store_true", help="Enable verbose output")

    args = parser.parse_args()

    # Connect to Mini-Arm
    print(f"Connecting to Mini-Arm on {args.port}...")
    client = MiniArmClient(port=args.port, baudrate=args.baudrate, verbose=args.verbose)

    if not client.connected:
        print("❌ Failed to connect to Mini-Arm")
        print("   Check port name and ensure device is connected")
        return 1

    print("✅ Connected successfully!\n")

    if args.interactive:
        print("Interactive mode - type 'exit' or 'quit' to exit")
        print("Type 'help' to see available commands\n")

        while True:
            try:
                cmd = input("mini-arm> ").strip()
                if cmd.lower() in ["exit", "quit", "q"]:
                    break
                if cmd:
                    client.send(cmd)
                    time.sleep(0.1)
                    response = client.get_buffer()
                    if response:
                        print(response)
            except KeyboardInterrupt:
                print("\n")
                break
            except EOFError:
                break
    else:
        # Send single command
        client.send(args.command)
        time.sleep(0.5)
        response = client.get_buffer()
        if response:
            print(response)

    print("\n✅ Disconnecting...")
    client.disconnect()
    return 0


if __name__ == "__main__":
    sys.exit(main())

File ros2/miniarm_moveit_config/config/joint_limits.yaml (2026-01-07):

# joint_limits.yaml allows the dynamics properties specified in the URDF to be overwritten or augmented as needed
# Specific joint properties can be changed with the keys [max_position, min_position, max_velocity, max_acceleration]
# Joint limits can be turned off with [has_velocity_limits, has_acceleration_limits]

# As MoveIt! does not support jerk limits, the acceleration limits provided here are the highest values that guarantee
# that no jerk limits will be violated. More precisely, applying Euler differentiation in the worst case (from min accel
# to max accel in 1 ms) the acceleration limits are the ones that satisfy
# max_jerk = (max_acceleration - min_acceleration) / 0.001

joint_limits:
  miniarm_joint1:
    has_velocity_limits: true
    max_velocity: 2.1750
    has_acceleration_limits: true
    max_acceleration: 3.75
  miniarm_joint2:
    has_velocity_limits: true
    max_velocity: 2.1750
    has_acceleration_limits: true
    max_acceleration: 1.875
  miniarm_joint3:
    has_velocity_limits: true
    max_velocity: 2.1750
    has_acceleration_limits: true
    max_acceleration: 2.5
  miniarm_joint4:
    has_velocity_limits: true
    max_velocity: 2.1750
    has_acceleration_limits: true
    max_acceleration: 3.125
  miniarm_joint5:
    has_velocity_limits: true
    max_velocity: 2.6100
    has_acceleration_limits: true
    max_acceleration: 3.75
  miniarm_joint6:
    has_velocity_limits: true
    max_velocity: 2.6100
    has_acceleration_limits: true
    max_acceleration: 5.0
  miniarm_gripper_joint:
    has_velocity_limits: true
    max_velocity: 0.1
    has_acceleration_limits: false
    max_acceleration: 0.0

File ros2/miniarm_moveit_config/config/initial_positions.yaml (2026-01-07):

# Default initial positions for the miniarm's ros2_control fake system
initial_positions:
  miniarm_joint1: 0.0
  miniarm_joint2: -0.785
  miniarm_joint3: 0.0
  miniarm_joint4: -2.356
  miniarm_joint5: 0.0
  miniarm_joint6: 1.571

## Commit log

2023-03-18 main control code and utils library. Need to test on Pico W
2023-03-26 Major update including code and readme
    Finally pushing all the files for the Mini Arm project!
    [bom.xlsx]
2023-05-09 Major update to controller, robot object, kinematic solver, and models
    This is a major update to the codebase. After a month of testing out different kinematic solvers and investigating other Github repos working with robot arms, I've settled with the current configurat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
    Major revisions:
    - Added the `3d_files` subfolder to hold the actual models for the robot
    - Added the `test` subfolder to document the different libraries tested
    -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
    [Arm 01.STL, Arm 02 v3.STL, Arm 03.STL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]
2023-05-13 Updated to now parse controller commands from a connected xbox client
    And some touchups to comments
    [bom.xlsx]
2023-05-22 Inverse Kinematic and Trajectories now supported!
    Major announcement: Inverse Kinematics can now be handled! YAY!
    The `robotarm` module now has a `Robot` class with the preconfigured forward kinematic transform from the base to the gripper, given the physical parameters of the arm and the axes of rotations for e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
    The controller n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
2023-12-04 Major updates to robot firmware
    Major updates:
    1) Robot models have been updated, created in Solidworks but STL files should be the same
    2) Servo models downloaded for the complete assembly
    3) urdf created in `urdf_export` package, will be necessary for ROS2 drivers, need to do some organization later
    4) New option to set whether to use console direct communication and the `usb_cdc` package, or by using the UART pins for TX/RX communication from the builtin `board` package.
    Minor changes:
    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
    [Arm 01.SLDPRT, Arm 02 v3.SLDPRT, Arm 03.SLDPRT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]
2023-12-10 movemotor working, ik math correct but servos still need tweaking
    Same problem as before but now it seems closer to the joint offset and orientation (clockwise or counterclockwise rotation for the physical model to match the ik calculations
    [Base.SLDPRT, MiniArm Assembly.SLDASM, electronics deck.SLDPRT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]
2024-04-20 Simulation set to true at default, minor servo bug
    [Arm 01.STL, Arm 02 v3.STL, Arm 03.STL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]
2024-12-23 new commands and trajectory logging
    [90deg_shelf_2mmhole.SLDPRT, 90deg_shelf_2mmhole.STL, Arm 01.SLDPRT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]
2025-01-01 repo revamp
    [90deg_shelf_2mmhole.SLDPRT, 90deg_shelf_2mmhole.STL, Arm 01.SLDPRT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]
2025-01-06 launch arguments
    [miniarm.urdf]
2025-02-27 fixed models
    [17mm-mini-USB_connector-panel.SLDPRT, 17mm-mini-USB_connector-panel.STL, 28mm-mini-USB_connector-panel.SLDPRT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]
2025-03-04 changing delimiter to ENTER key
    [28mm-mini-USB_connector-panel.STL, 90deg_shelf_2mmhole.STL, Gripper base_old.SLDPRT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]
2025-08-21 circuitpython support
    [MiniArm Assembly.SLDASM, gripper assembly.SLDASM, yumi.urdf]
2025-12-12 Reorganize project structure and improve documentation
    - Organized tests/ into categories:
    - hardware/ - Serial and servo tests
    - kinematics/ - IK solver validation
    - networking/ - Communication tests
    - visualization/ - 3D rendering tests
    - Created examples/ with organized demos:
    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
2026-01-07 Major restructure: professional package layout, refactored client, Sphinx docs
    - Reorganized to professional structure: src/, firmware/, hardware/, ros2/
    - Refactored MiniArmClient with all Pico commands (motion, joints, gripper, LED, trajectory)
    - Added pyproject.toml for pip installation
    - Created Sphinx documentation with Furo theme
    - Added GitHub Actions for docs deployment and tests
    - Added unit tests (18 tests passing)
    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
    [17mm-mini-USB_connector-panel.SLDPRT, 17mm-mini-USB_connector-panel.STL, 28mm-mini-USB_connector-panel.SLDPRT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]
2026-01-07 Move Python code to ros2/miniarm_core for unified ROS2 installation
    - Created miniarm_core as ament_python ROS2 package
    - Moved src/mini_arm/ contents to ros2/miniarm_core/miniarm_core/
    - Updated pyproject.toml to build from new location
    - Package name on PyPI remains 'mini-arm', import is 'miniarm_core'
    - ROS2 users: ln -s ros2/* into workspace, colcon build
    - Pip users: pip install mini-arm (still works)
    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
2026-01-07 Fix linting and formatting issues for CI
    [__main__.py, client.py]
2026-10-23 Checkpoint bounded arm controls, gripper camera firmware, and repaired ROS model

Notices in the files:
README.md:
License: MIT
